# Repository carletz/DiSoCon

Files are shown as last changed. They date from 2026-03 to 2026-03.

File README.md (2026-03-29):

# ☀️ DiSoCon2 — Differential Solar Controller V2

> **A fully open-source, ESP32-S3 based differential solar thermal controller with dual-tank switching, PT1000 sensing, TRIAC pump control, and Ethernet/MQTT connectivity.**






---

## 🌡️ What Is This?

DiSoCon2 is a modular, open-hardware differential solar thermal controller designed to intelligently manage a domestic solar hot water system with **multiple storage tanks**. It replaces proprietary "dumb" controllers with a fully integrated, home-automation-aware solution built around the **ESP32-S3** and **ATmega32U4**.

The system reads four PT1000 platinum resistance sensors (solar collector, primary tank, secondary tank, return line), computes temperature differentials, and drives pumps and 3-way valves accordingly — all while reporting live data to **Home Assistant** via MQTT or **Ethernet**.

**V2 integrates the control logic and the analog temperature measurement circuitry onto a single board**, eliminating the inter-board wiring of V1 and improving signal integrity.

---

## 🎯 Key Features

| Feature | Detail |
|---|---|
| **Temperature sensing** | 4× PT1000 via precision OPV front-end (MCP6004, ±0.1% resistors) + DS18B20 OneWire bus |
| **Pump control** | 2× TRIAC outputs (BTA41-600B + MOC3021) for 230V AC pumps, with zero-cross synchronization |
| **Valve control** | 2× relay outputs (SRD-05VDC) for 3-way motorized valves, optoisolated via PC817C |
| **Connectivity** | W5500 Ethernet (SPI) + ESP32-S3 onboard WiFi/BLE |
| **Field bus** | RS-485 half-duplex via MAX13487E (auto-direction), with 120Ω termination and SMBJ6.8A TVS protection |
| **User interface** | 20×4 I2C LCD + 5-button keypad (UP / DOWN / LEFT / RIGHT / OK) read via ADS1115 |
| **Power supply** | HLK-PM01 mains-to-5V module + BL1117-33CX LDO for 3.3V logic; USB-C 5V input as alternative |
| **Safety** | Anti-freeze logic, overheating protection, fuse-protected AC input, snubber networks on all TRIAC outputs |
| **Firmware** | ESPHome YAML on ESP32-S3; ATmega32U4 Arduino firmware for analog front-end |

---

## 🧩 System Architecture

The project is split into two physically separate boards that connect via a 10-pin IDC ribbon:

```
┌─────────────────────────────────────────────────┐
│              CONTROL BOARD (Full Board V2)      │
│                                                 │
│  ┌──────────┐  ┌──────────┐  ┌───────────────┐  │
│  │ ATmega   │  │ ESP32-S3 │  │  W5500        │  │
│  │ 32U4     │◄─► (main    │  │  Ethernet     │  │
│  │ PT1000   │  │  ESPHome)│  │  Controller   │  │
│  │ front-end│  └────┬─────┘  └───────────────┘  │
│  └──────────┘       │                           │
│  ┌──────────┐  ┌────┴─────┐  ┌───────────────┐  │
│  │ MCP6004  │  │ MAX13487 │  │  ADS1115      │  │
│  │ 4ch OPV  │  │  RS-485  │  │  Button ADC   │  │
│  └──────────┘  └──────────┘  └───────────────┘  │
└─────────────────────┬───────────────────────────┘
                      │ 10-pin ribbon (CN3)
┌─────────────────────┴───────────────────────────┐
│              POWER BOARD (Power Board V2)       │
│                                                 │
│  ┌──────────┐  ┌──────────────┐  ┌───────────┐  │
│  │ HLK-PM01 │  │ 2× BTA41     │  │ 2× SRD    │  │
│  │ AC→5V    │  │ TRIAC pumps  │  │ relays    │  │
│  └──────────┘  │ + MOC3021    │  │ valves    │  │
│                │ + snubber    │  └───────────┘  │
│  ┌──────────┐  └──────────────┘                 │
│  │ ZeroCross│  MB10S bridge + LTV-817C          │
│  │ detector │  → ZEROCROSS signal to ESP32      │
│  └──────────┘                                   │
└─────────────────────────────────────────────────┘
```

<div align="center">
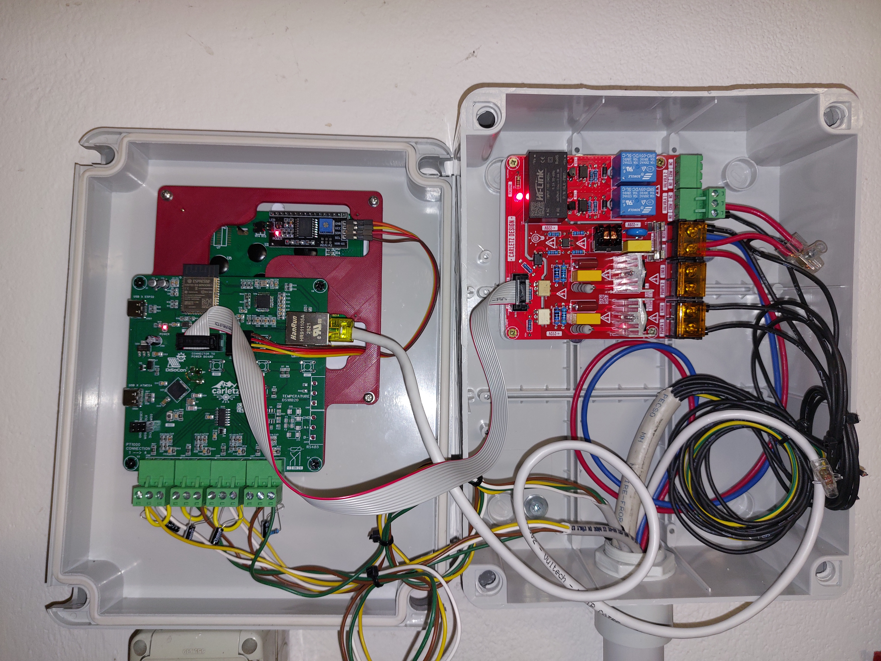
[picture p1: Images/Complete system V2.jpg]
    
</div>

---

## 📐 Hardware Details

### Control Board — Full Board V2.0 (6-page schematic)

<div align="center">
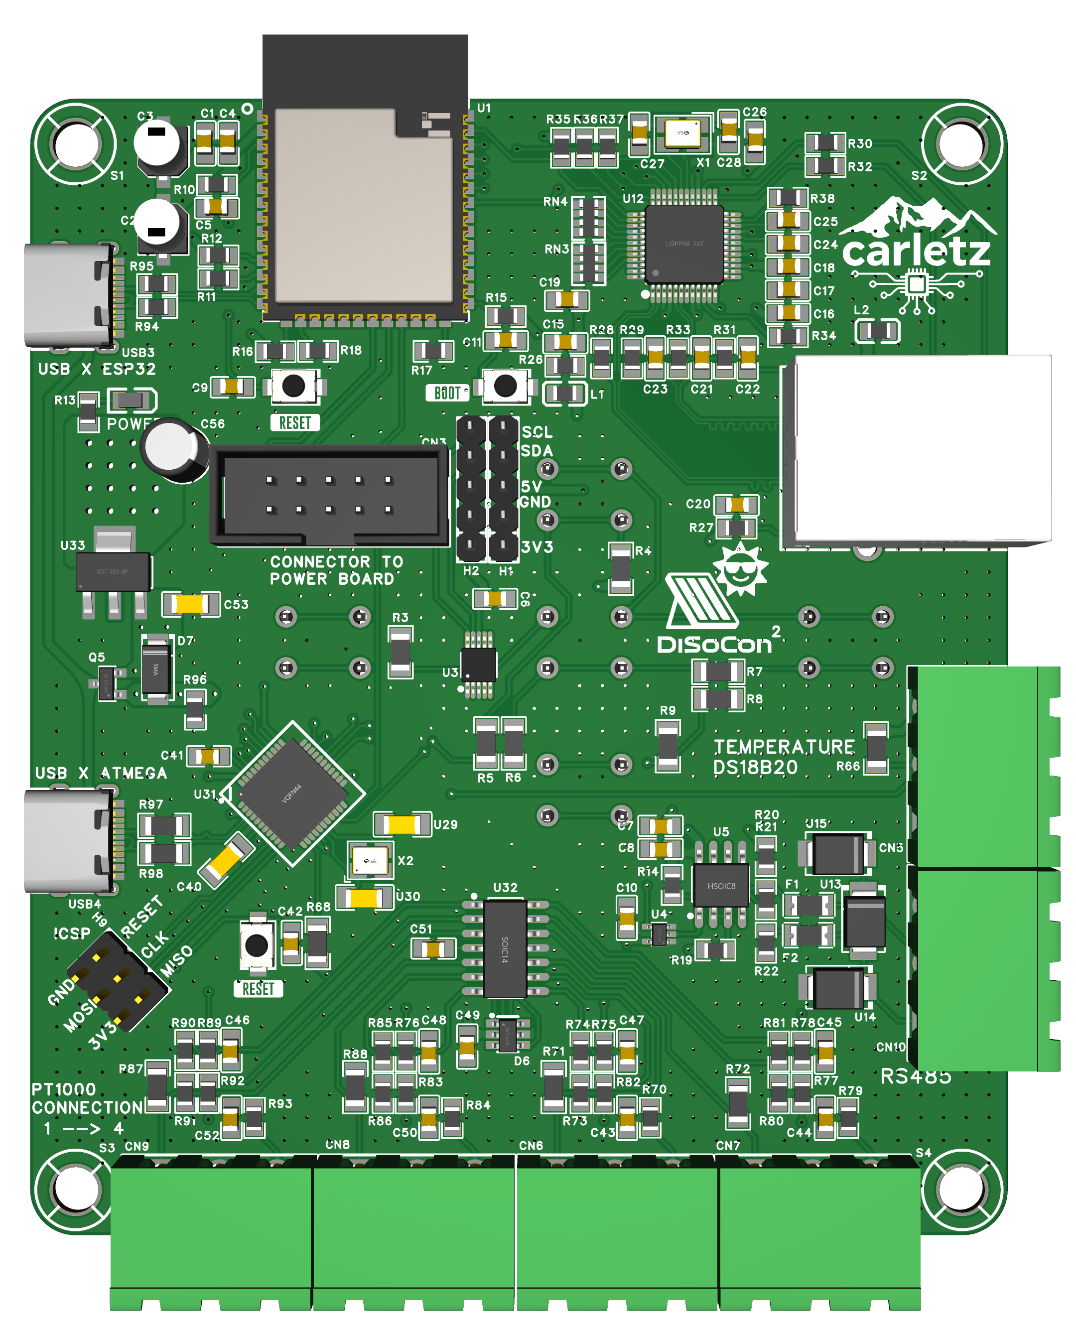
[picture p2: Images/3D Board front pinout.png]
    
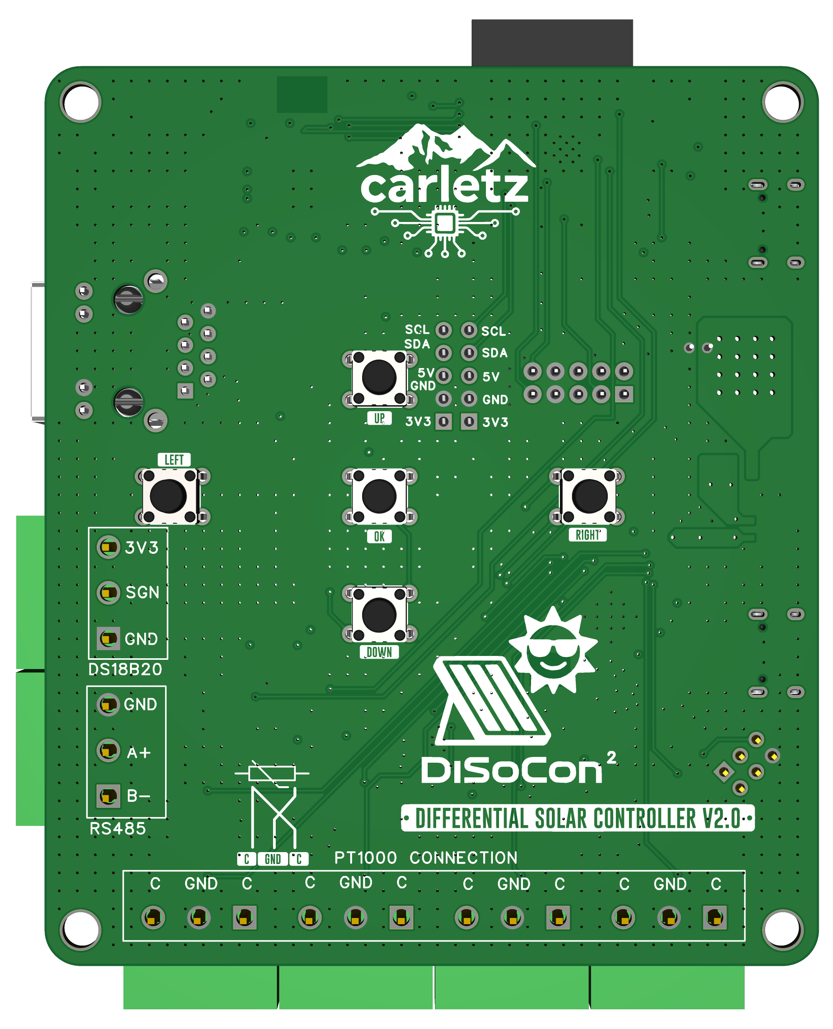
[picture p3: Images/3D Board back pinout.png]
    
</div>

#### Page 1 · Microcontroller & Power

- **ESP32-S3** (U1) — main application processor running ESPHome. Controls all outputs, reads sensors, manages Ethernet and RS-485.
- **ATmega32U4** (U31) — dedicated analog co-processor. Drives the PT1000 OPV front-end, sends converted temperature values to the ESP32-S3 via UART (`TEMP-TX` / `TEMP-RX`). Has its own USB-C (USB4) for independent firmware upload and an ICSP header (H9) for UPDI/ISP programming.
- **3.3V power**: BL1117-33CX LDO (U33) fed from the 5V rail. Protected by a WPM2015-3 P-FET ORing between USB-C 5V (USB5V) and board 5V (+5VP), with a 1N5819 Schottky for reverse-polarity protection.
- RESET and BOOT tactile buttons for ESP32-S3; RESET button also present for ATmega32U4.
- Power LED (XL-2012SURC red) on 3.3V via 1kΩ.

#### Page 2 · Ethernet

- **W5500** (U12) — hardware TCP/IP offload chip connected to ESP32-S3 via SPI1 (`SPI1_MOSI/MISO/SCK/CS`). Reset line (`RST_NET`) and interrupt line (`INT_NET`) connected to dedicated ESP32-S3 GPIOs.
- Magnetics: **HR911105A** integrated RJ45 with built-in transformer (1CT:1CT) and LEDs — LINK (yellow) and ACT (green).
- 25MHz crystal (X1) for W5500 clock. Pi-filter (HCB2012KF-121T50 ferrite beads L1/L2) on the 3.3VNET rail for noise isolation.
- Proper termination: 49.9Ω series resistors on TX pairs; 82Ω series on RX pairs; 6.8nF and 10nF AC coupling capacitors; 22nF center-tap capacitor.
- W5500 PMODE pins floating (auto-negotiate 10/100 with auto-MDIX).

#### Page 3 · I/O, PCF8574 & LCD

- **5-button keypad**: UP, DOWN, LEFT, RIGHT, OK (KH-6X6X8H-TJ tactile switches) wired to an **ADS1115** (U3) via a resistive voltage divider (1kΩ + 1MΩ pull-down). The ADS1115 reads button combinations on AIN0; ALERT/RDY can generate interrupts.
- **PCF8574M** (U9) — 8-bit I2C I/O expander that buffers output signals (MOTORE1-3, VALVOLA1-2, ZEROCROSS) to the Power Board via the **SN74HCT14** (U10) Schmitt-trigger hex inverter. Note: this path is **not suitable for PWM signals** (as marked on the schematic).
- **20×4 I2C LCD** (LCD1) connected via a standard PCF8574-based I2C backpack module.
- Two 5-pin I2C expansion headers (H1, H2) provide 3.3V / 5V, SDA, SCL for external I2C peripherals.
- 10-pin IDC connector (CN3) carries all inter-board signals: MOTORE1, MOTORE2, ZEROCROSS, VALVOLA1, VALVOLA2, 3.3V, 5V, +5VP (relay coil), GND.

#### Page 4 · RS-485

- **MAX13487EESA+T** (U5) — half-duplex RS-485 transceiver with integrated auto-direction control (no DE/RE GPIO needed). VCC at 5V, with a `SN74LVC1G125` (U4) level shifter on the RO output to convert from 5V to 3.3V logic for ESP32-S3 RX.
- **120Ω** termination resistor (R21) across A/B lines.
- **4.7kΩ** fail-safe bias resistors (R20, R22) on A and B.
- **SMBJ6.8A** TVS diodes (U13, U14, U15) on A line, B line, and GND for surge/ESD protection on the RS-485 bus.
- Self-resetting polyfuses (F1, F2: nSMD005) on A and B lines.
- Screw terminal connector (CN10: WJ2EDGRC-5.08-3P) for field wiring.

#### Page 5 · ATmega32U4

- **ATmega32U4-MU** (U31) in QFN-44 package. Clocked at 16MHz (crystal X2 with 22pF load caps U29/U30).
- USB (D+/D-) protected by a **DALC208SC6** (D8) ESD array with 22Ω series resistors (R97, R98).
- ICSP/SPI header H9 exposes MOSI, MISO, CLK, RESET for external programmer access.
- Communicates with ESP32-S3 via UART: `PD2(RXD1)` → `TEMP-RX` on ESP32; `PD3(TXD1)` → `TEMP-TX`.
- ADC pins PF0–PF7 connected to the OPV amplifier outputs (TEMP_OUT1–4) and enable signals (TEMP_ENB1–4) controlled by PC7/PC6/PB6/PB5.
- `OPV_ENB` line (PC7 / PE2) allows the ATmega to power-gate the entire OPV section.
- OneWire DS18B20 bus on a separate 3-pin screw terminal (CN5) with 4.7kΩ pull-up (R66).

#### Page 6 · PT1000 Amplifier

- **MCP6004T-I/SL** (U32) — quad rail-to-rail op-amp, all four channels used, one per PT1000 sensor.
- Each channel implements an **inverting amplifier** with gain set by a ±0.1% tolerance 9.1kΩ feedback resistor (R90/R85/R74/R81) and 1kΩ input resistor (R91/R86/R75/R80). This gives a gain of –9.1.
- 1MΩ resistors (R87/R88/R71/R72) provide a DC bias path to the non-inverting input (tied to GND reference).
- Each output is low-pass filtered: 1kΩ (R89/R76/R78/R73) + 1µF (C46/C48/C47/C45) forming a ~160Hz corner frequency to reject switching noise.
- Per-channel enable switches (`TEMP_ENB1–4`) built from 4.7kΩ / 4.7kΩ resistor pairs allow the ATmega to multiplex or disable channels individually.
- **DALC208SC6** (D6) ESD protection array on all four sensor input lines (IN+1 through IN+4) before they reach the OPV inputs.
- OPV supply (VDD/VSS) bypassed with 100nF (C51/C52), power-gated via `OPV_ENB`.
- PT1000 connectors: CN9 / CN8 / CN6 / CN7 (WJ2EDGRC-5.08-3P screw terminals, one per sensor channel).

---

### Power Board — Power Board V2.0 (2-page schematic)

<div align="center">
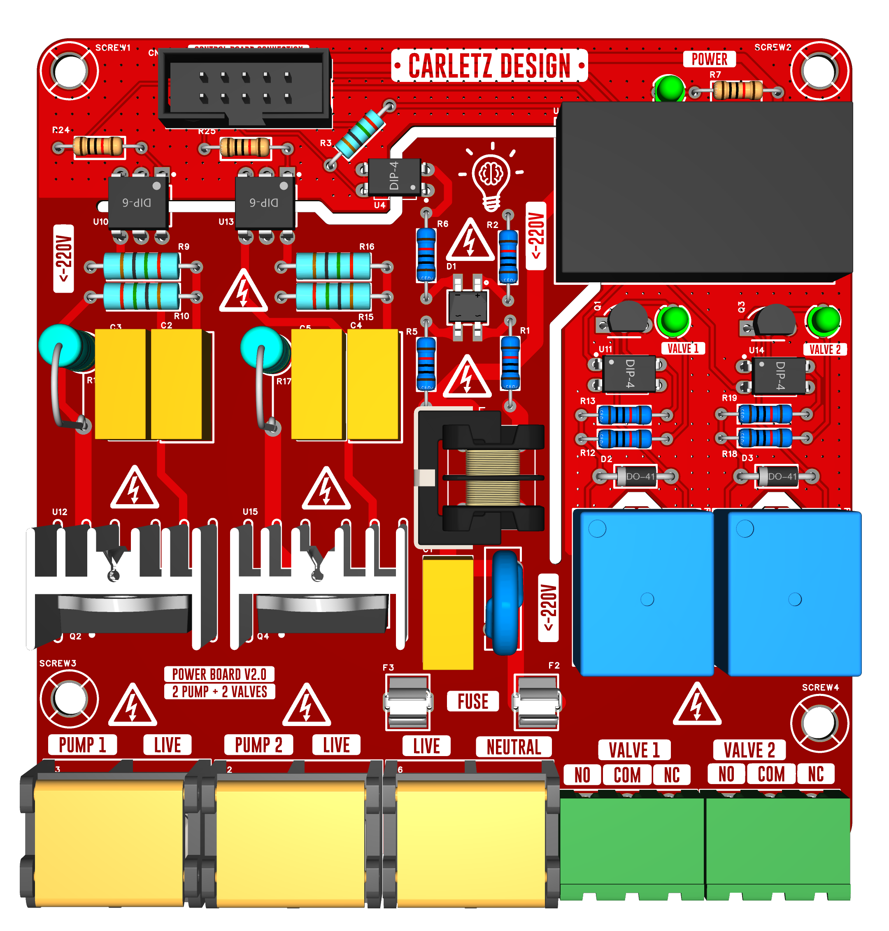
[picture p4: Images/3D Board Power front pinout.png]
    
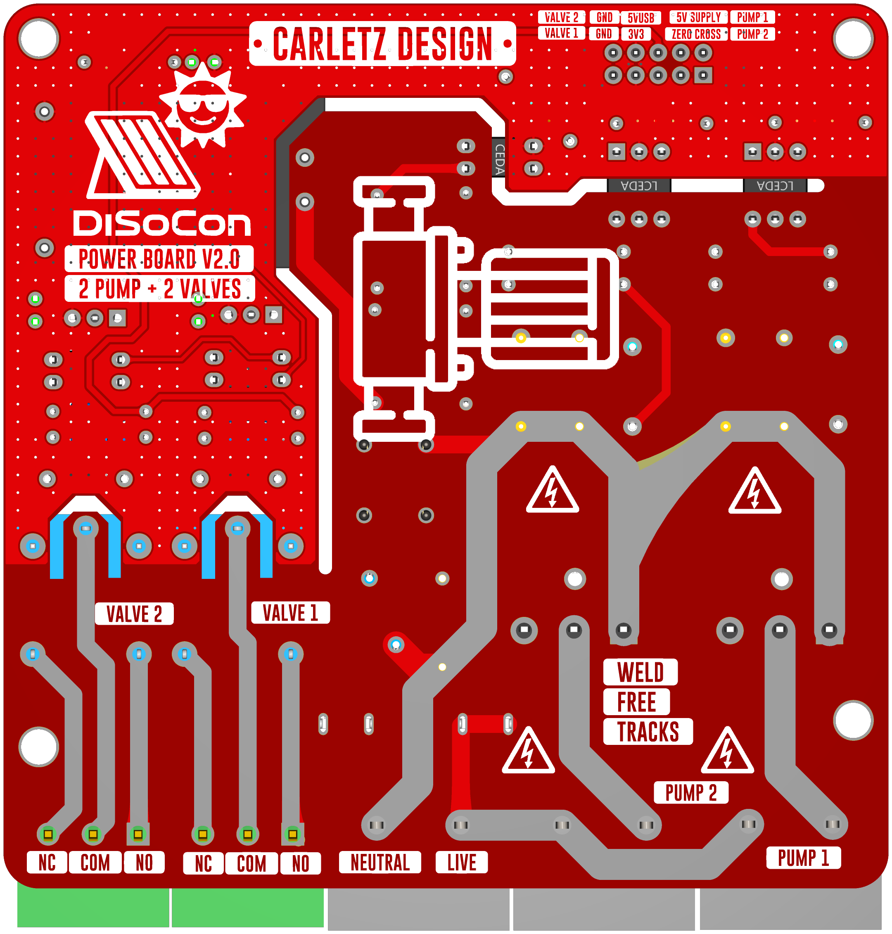
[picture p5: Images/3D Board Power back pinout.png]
    
</div>

#### Page 1 · Power Supply, Connector & Relays

- **AC mains input** enters through a 5×20mm fuse (F2/F3) and a varistor (R4: RM10D561KD24E100) + EMI filter choke (L1: UU9.8Y-10mH) before reaching the **HLK-PM01** (U8) isolated AC-DC module, which outputs 5VDC. A 100nF capacitor (C1) on the AC side suppresses differential-mode noise.
- An additional slow-blow fuse (F4: 5G.300021) provides secondary protection.
- The 5V rail powers relay coils, optocouplers, and feeds through the 10-pin IDC (CN3) to the control board.
- **POWER LED** indicator on the Power Board side.
- AC line (L, N) also distributed to motor output screw terminals (M1, M2) and to TRIAC load outputs.
- **DBT50G-9.5-2P** connectors (U2, U3, U6) for L, N, and motor output wiring.
- Four PCB screw posts (SCREW1–4) for chassis/DIN rail mounting.

**Relay section (Valve 1 & Valve 2):**
- Two identical circuits, each using:
  - **BC547** NPN transistor (Q1, Q3) to drive the relay coil from a 3.3V logic signal via 1kΩ base resistor.
  - **SRD-05VDC-SL-C** 5V SPDT relay (RLY1, RLY2) switched by the transistor.
  - **1N4007** flyback diode (D2, D3) across the relay coil.
  - **PC817C** optocoupler (U11, U14) provides galvanic isolation between logic-side (`VALVOLA1/2` signals, 3.3V-fed via 1kΩ) and the relay driver side (5VUSB referenced). Output resistor 1kΩ.
  - RELE' LED indicators (green XL-2012SURC via 220Ω) for visual relay status.
  - 3-pin screw terminal outputs (CN1, CN2) for valve wiring.

#### Page 2 · TRIAC Firing & Zero-Cross Detection

**TRIAC circuits (Pump 1 & Pump 2) — identical topology:**
- **MOC3021M** (U10, U13) — non-zero-crossing TRIAC optocoupler (zero-cross sync is handled in software using the ZEROCROSS signal). LED drive current set by 150Ω / 100Ω resistors (R24/R25) on the logic side.
- Gate current limiting resistor 360Ω (R9, R15) + snubber network: 47nF (C2/C4) + 100Ω (R11/R17) in series across the TRIAC, plus 100nF (C3/C5) across the main terminals.
- Gate-side 470Ω resistor (R10, R16) to limit peak gate current into the TRIAC.
- **BTA41-600BRG** (Q2, Q4) — 40A/600V TO-220 TRIAC. Rated far above typical domestic pump currents for long-term reliability and inrush tolerance.
- **XSD1226-307** (U12, U15) — TRIAC thermal fuse (307°C) in series with the gate resistor for thermal runaway protection.
- Output screw terminals for motors M1 and M2 (Line + Neutral).

**Zero-cross detection:**
- **MB10S** bridge rectifier (D1) connected directly across Line (LP) and Neutral (NP) through four 47kΩ resistors (R1/R2/R5/R6) as a current limiter (total ~188kΩ into a 230V mains, ≈1.2mA peak).
- **LTV-817-C** (U4) optocoupler with 10kΩ pull-up (R3) on the output side (3.3V). Generates the `ZEROCROSS` signal — a pulse train at twice the mains frequency (100Hz for 50Hz mains) that is routed to the ESP32-S3 for phase-synchronised TRIAC firing.

---

## 🔌 Inter-Board Connector Pinout (CN3 — DC3-2.54-10PAS)

| Pin | Signal | Direction | Description |
|---|---|---|---|
| 1 | MOTORE2 | PB → CB | Pump 2 control signal |
| 2 | MOTORE1 | PB → CB | Pump 1 control signal |
| 3 | ZEROCROSS | PB → CB | Zero-cross detection pulse |
| 4 | 5V | PB → CB | 5V power from HLK-PM01 |
| 5 | 3V3 | CB → PB | 3.3V logic reference |
| 6 | 5VUSB | CB → PB | USB 5V (relay coil supply) |
| 7 | — | — | (reserved/GND) |
| 8 | VALVOLA1 | CB → PB | Valve 1 control |
| 9 | VALVOLA2 | CB → PB | Valve 2 control |
| 10 | GND | — | Common ground |

> CB = Control Board, PB = Power Board

---

## 🌡️ PT1000 Sensing: Recommended Wiring

Each PT1000 connects to a 3-pin screw terminal on the Control Board (CN6–CN9). The sensor is wired in a **2-wire configuration** to the OPV input. For best accuracy, use matched cable runs and consider the per-channel gain/offset calibration available in the ATmega firmware.

| Connector | Sensor Location | Signal |
|---|---|---|
| CN9 | Solar collector (panel) | IN+1 → TEMP_OUT1 |
| CN8 | Primary storage tank | IN+2 → TEMP_OUT2 |
| CN6 | Return / secondary circuit | IN+3 → TEMP_OUT3 |
| CN7 | Secondary tank / boiler outlet | IN+4 → TEMP_OUT4 |

---

## ⚙️ Control Logic Overview

The ESP32-S3 implements the following logic layers in ESPHome:

1. **Temperature acquisition** — ATmega32U4 reads 4× PT1000 channels via the OPV front-end, applies per-channel IIR filtering and gain/offset calibration, and streams the values over UART to the ESP32-S3.
2. **Differential control (ΔT)** — Compares solar collector temperature against tank temperatures. Activates `MOTORE1` (solar pump) when ΔT exceeds a configurable threshold; deactivates with hysteresis.
3. **Dual-tank switching** — Activates `VALVOLA1` / `VALVOLA2` to direct hot fluid to the tank with the lowest temperature, maximising energy storage.
4. **Secondary pump** — `MOTORE2` manages heat exchange with the gas boiler loop based on secondary tank differentials.
5. **Protections**:
   - **Anti-freeze**: Forces pump on when collector temperature drops below a configurable minimum.
   - **Overheating**: Limits pump runtime or diverts flow when tank temperature exceeds maximum.
   - **Sensor fault**: Detects open-circuit (NaN, T < –10°C) or short-circuit (T > 200°C) PT1000 conditions.
6. **TRIAC zero-cross firing** — Pump activation is synchronised to the mains zero-crossing via the `ZEROCROSS` interrupt for reduced EMI and inrush.

<div align="center">
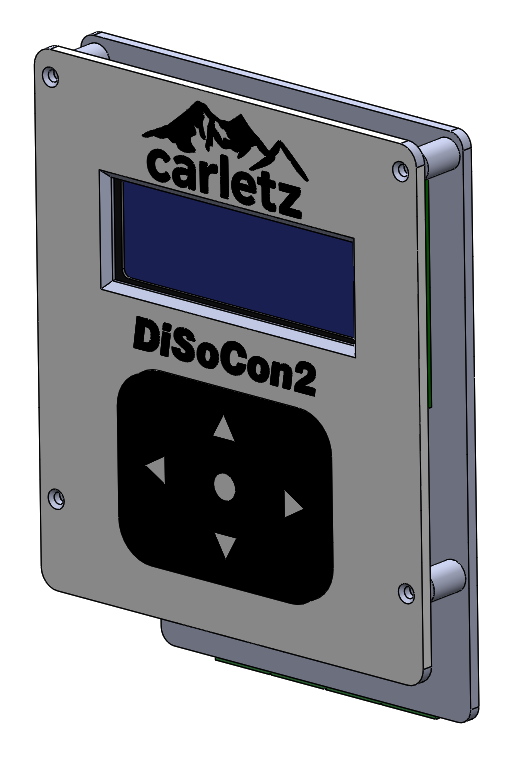
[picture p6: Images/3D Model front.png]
    
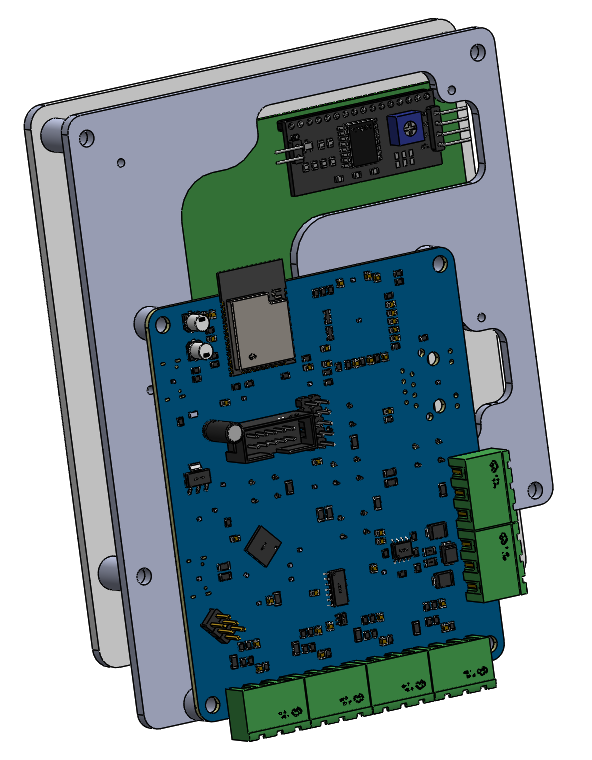
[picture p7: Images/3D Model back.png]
    
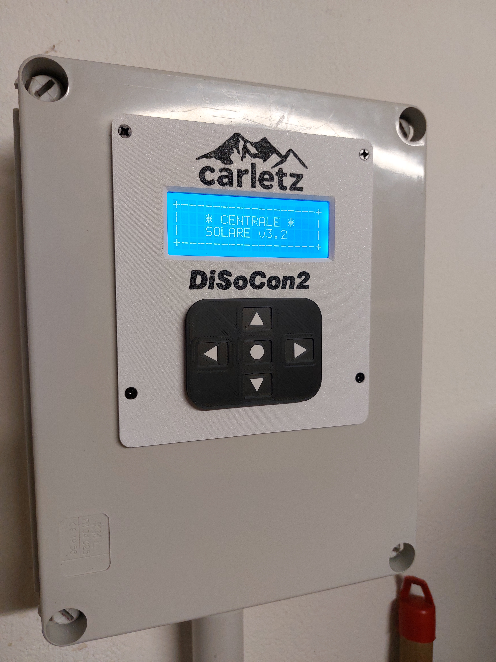
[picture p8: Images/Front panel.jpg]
    
</div>

---

## 📁 Repository Structure

```
DiSoCon/
├── 3D Model/                         # 3D renders and model files
├── Hardware/                         # Schematics, PCB Gerbers, EasyEDA sources
│   ├── SCH_Full_Board_V2.0.pdf       # Control board schematic (6 pages)
│   └── SCH_Power_Board_V2.0.pdf      # Power board schematic (2 pages)
├── Images/                           # Board renders, photos, diagrams
├── Software/                         # Firmware source code
│   ├── ESPHome YAML                  # ESPHome configuration for ESP32-S3
│   └── ATmega32U4/                   # Arduino sketch for PT1000 co-processor
├── LICENSE
└── README.md
```

---

## 🚀 Getting Started

### 1. Hardware

- Order PCBs from Gerber files (JLCPCB)
- Assemble the Power Board first; verify 5V output before connecting the Control Board
- Flash the ATmega32U4 via ICSP header H9 (Arduino Nano as ISP or dedicated programmer)
- Flash ESPHome to the ESP32-S3 via USB-C (USB3 connector)

### 2. Firmware

```bash
# Clone the repo
git clone https://github.com/carletz/DiSoCon

# Flash ESPHome (first time via USB)
esphome run Software/main.yaml

# Subsequent updates via OTA (Ethernet or WiFi)
```

### 3. Home Assistant Integration

Add the device to ESPHome dashboard. All sensors, pumps, and valve states are automatically exposed as Home Assistant entities. MQTT topics follow ESPHome conventions.

---

## ⚠️ Safety & Disclaimer

> **This project involves mains voltage (230V AC). Working with mains voltage is potentially lethal.**

This project is provided **for educational and inspiration purposes only**. The author(s) accept **no responsibility** for damage to equipment, persons, or property arising from the use of this design.

Any real-world installation must be performed by a **qualified electrician** in compliance with local electrical codes and safety regulations (e.g. IEC 60364 in Europe).

By using this material you acknowledge it is offered **as-is, without warranty of any kind**.

---

## 📅 Version History

| Version | Date | Notes |
|---|---|---|
| V2.0 | March 2026 | Integrated control + analog measurement on single board; ATmega32U4 co-processor; EasyEDA redesign |
| V1.0 | April 2025 | Separate controller and temperature measurement boards |

---

## 👤 Author

**carletz** — [@carletz on GitHub](https://github.com/carletz)

[YouTube: carletz](https://www.youtube.com/@carletzslug)

[OSHWLab: carletz](https://oshwlab.com/carletz.slug/works)

---

## 📜 License

This work — hardware schematics, PCB designs, firmware, and documentation — is licensed under the **Creative Commons Attribution-NonCommercial-ShareAlike 4.0 International License (CC BY-NC-SA 4.0)**.



**You are free to:**
- **Share** — copy and redistribute the material in any medium or format
- **Adapt** — remix, transform, and build upon the material

**Under the following terms:**
- **Attribution** — You must give appropriate credit, provide a link to the license, and indicate if changes were made.
- **NonCommercial** — You may not use the material for commercial purposes.
- **ShareAlike** — If you remix, transform, or build upon the material, you must distribute your contributions under the same license.

See [`LICENSE`](./LICENSE) for the full license text.

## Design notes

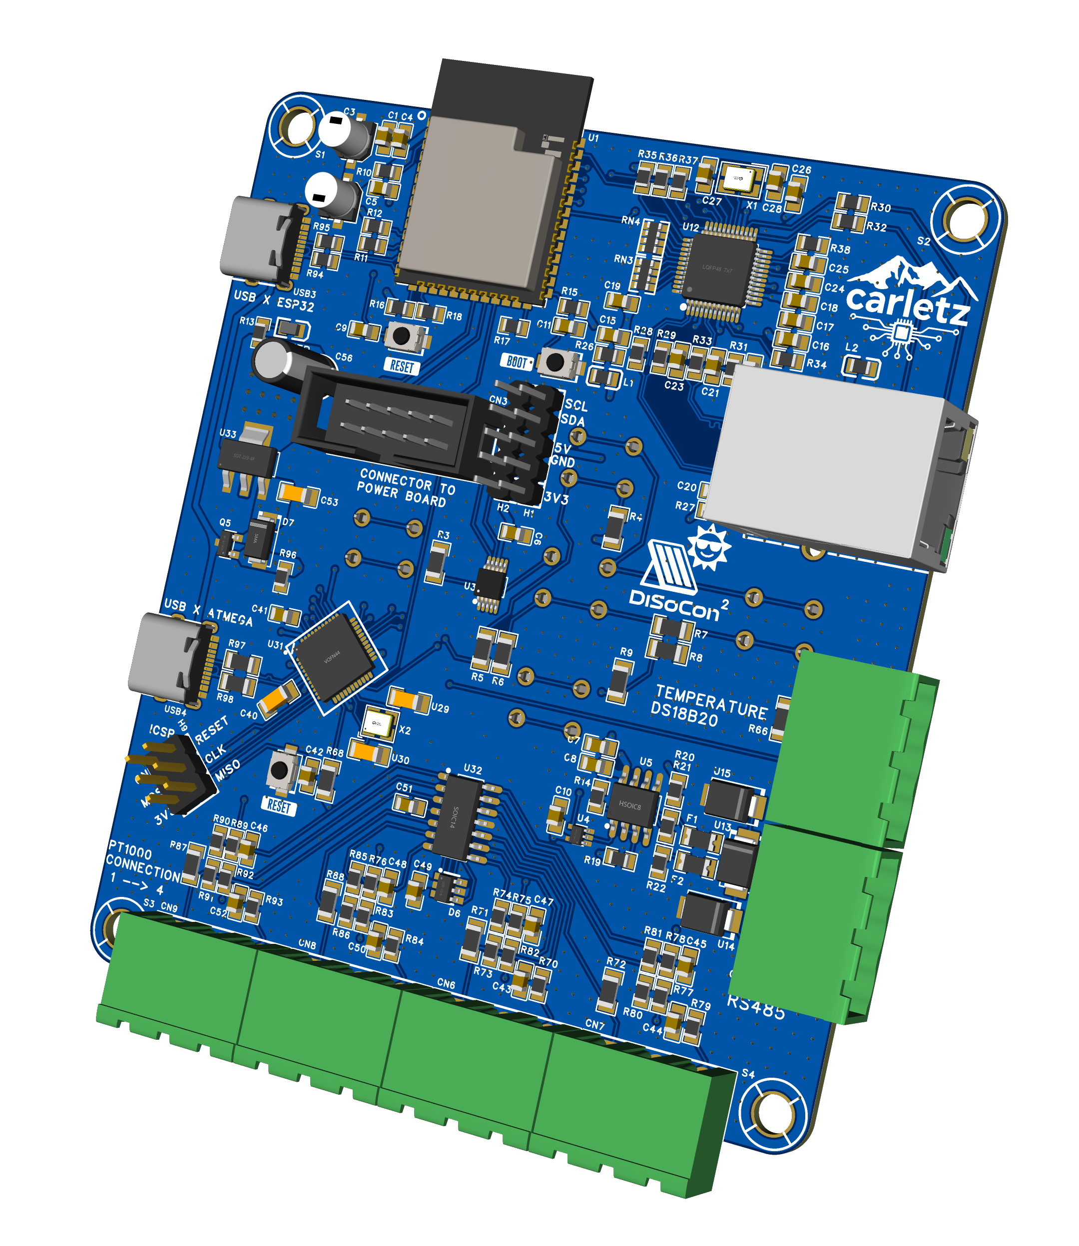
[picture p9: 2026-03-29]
Images/3D Board front.png

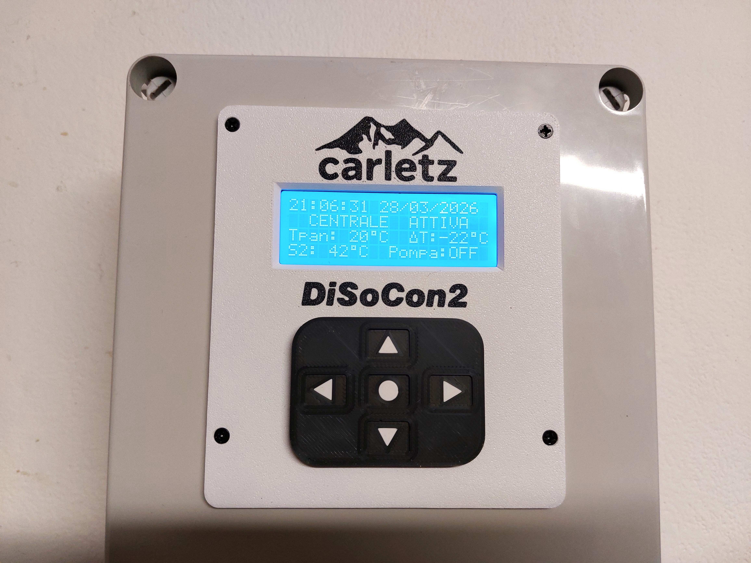
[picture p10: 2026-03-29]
Images/cover.jpg

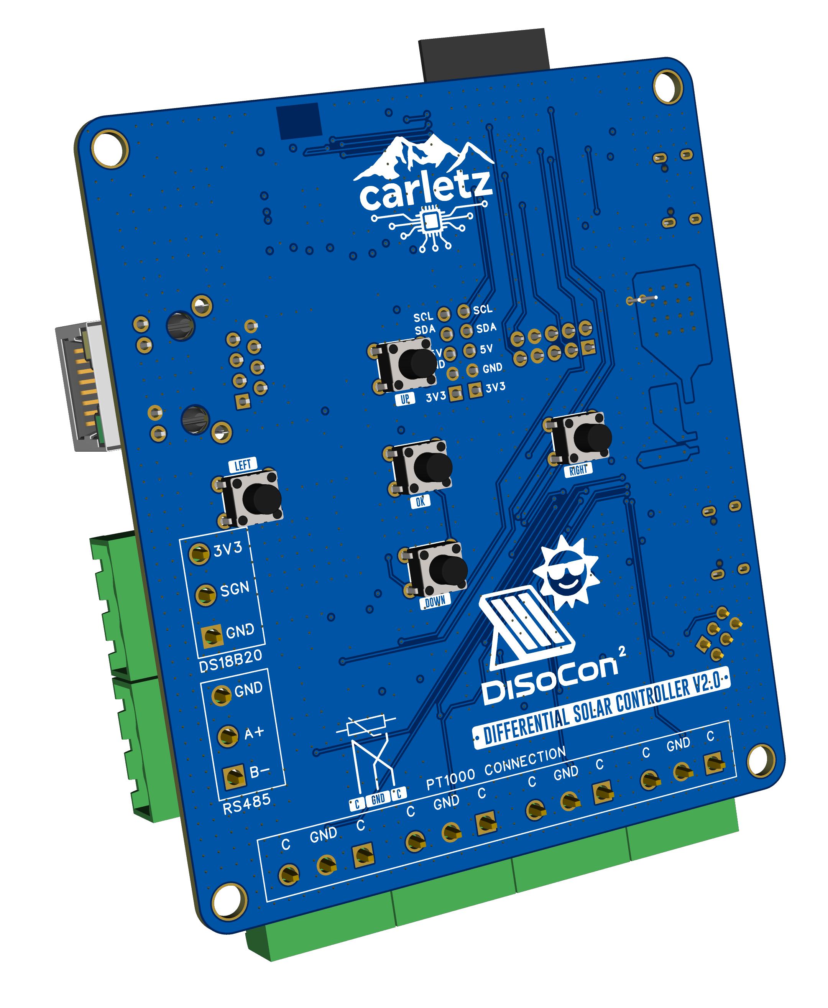
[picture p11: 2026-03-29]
Images/3D Board back.png

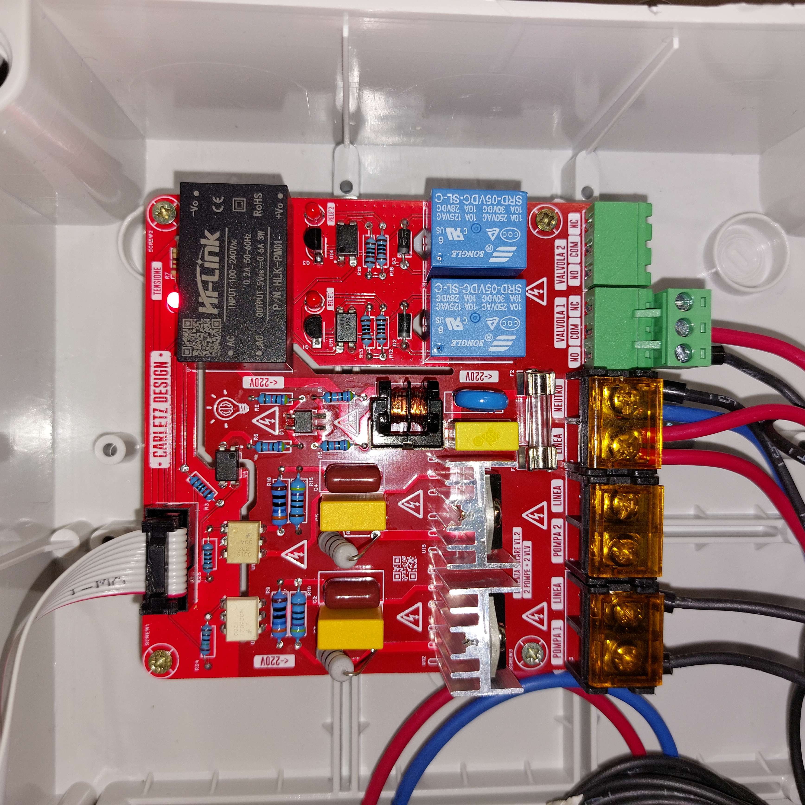
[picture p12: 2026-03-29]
Images/Power Board.jpg

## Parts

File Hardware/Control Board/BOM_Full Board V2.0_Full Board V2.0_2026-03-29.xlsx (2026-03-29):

No. | Quantity | Comment | Designator | Footprint | Value | Manufacturer Part | Manufacturer | Supplier Part | Supplier | LCSC Stock | LCSC Price | Primary Category | Secondary Category | Pin Count | JLCPCB Stock | JLCPCB Price | 3D Model Title | Device | Name | Unique ID | Convert to PCB | Add into BOM | Symbol
1 | 3 | TS-1088-AR02016 | ((BOOT)),((RESET)),((RESET)) | SW-SMD_L3.9-W3.0-P4.45 |  | TS-1088-AR02016 | XUNPU(讯普) | C720477 | LCSC |  |  | Switches | Tactile Switches | 2 | 655129 | 0.008 | SW-SMD_L3.9-W2.9-H2.0-LS4.8 | TS-1088-AR02016 | TS-1088-AR02016 | gge95,gge95_1,gge98 |  | yes
2 | 5 | KH-6X6X8H-TJ | ((DOWN)),((LEFT)),((OK)),((RIGHT)),((UP)) | SW-TH_4P-L6.0-W6.0-P4.50-LS6.5 |  | KH-6X6X8H-TJ | kinghelm(金航标) | C2837518 | LCSC |  |  | Key/Switch | Tactile Switches | 4 | 5232 | 0.0023 | SW-TH_4P-L6.0-W6.0-H7.0-P4.50-LS6.5_EVQPAE07K | KH-6X6X8H-TJ | KH-6X6X8H-TJ | gge35,gge36,gge37,gge38,gge39 |  | yes
3 | 3 | 10uF | C1,C7,C15 | C0805 | 10uF | CL21A106KOQNNNE | SAMSUNG(三星) | C1713 | LCSC |  |  | Capacitors | Multilayer Ceramic Capacitors MLCC - SMD/SMT | 2 | 1675133 | 0.0022 | C0805_L2.0-W1.3-H1.3 | CL21A106KOQNNNE | 10uF | gge199,gge200,gge201 |  | yes
4 | 2 | 10uF | C2,C3 | CAP-SMD_BD4.0-L4.3-W4.3-LS5.1-FD | 10uF | VE-100M1ATR-0405 | lelon(立隆) | C249449 | LCSC |  |  | Capacitors | Aluminum Electrolytic Capacitors - SMD | 2 | 0 | 0.009 | CAP-SMD_BD4.0-L4.3-W4.3-LS5.1-FD | VE-100M1ATR-0405 | 10uF | gge137,gge138 |  | yes
5 | 8 | 100nF | C4,C9,C11,C16,C17,C18,C19,C26 | C0805 | 100nF | CL21B104KCFNNNE | SAMSUNG(三星) | C28233 | LCSC |  |  | Capacitors | Multilayer Ceramic Capacitors MLCC - SMD/SMT | 2 | 3374865 | 0.0015 | C0805_L2.0-W1.3-H1.3 | CL21B104KCFNNNE | 100nF | gge211,gge212,gge213,gge214,gge215,gge216,gge217,gge218 |  | yes
6 | 2 | 1uF | C5,C6 | C0805 | 1uF | HHV0805R7105K101NSLJ | Chinocera(华瓷) | C22367837 | LCSC |  |  | Capacitors | Multilayer Ceramic Capacitors MLCC - SMD/SMT | 2 | 138361 | 0.0032 | C0805_L2.0-W1.3-H1.3 | HHV0805R7105K101NSLJ | 1uF | gge251,gge251_1 |  | yes
7 | 10 | 100nF | C8,C10,C41,C42,C43,C44,C49,C50,C51,C52 | C0805 | 100nF | C0805B104K500NT | TORCH(火炬) | C476766 | LCSC |  |  | Capacitors | Multilayer Ceramic Capacitors MLCC - SMD/SMT | 2 | 148715 | 0.0006 | C0805_L2.0-W1.3-H1.3 | C0805B104K500NT | 100nF | gge140,gge141,gge148,gge155,gge162,gge162_1,gge162_2,gge163,gge163_1,gge163_2 |  | yes
8 | 1 | 22nF | C20 | C0805 | 22nF | CC0805KRX7R9BB223 | YAGEO(国巨) | C107147 | LCSC |  |  | Capacitors | Multilayer Ceramic Capacitors MLCC - SMD/SMT | 2 | 399455 | 0.001 | C0805_L2.0-W1.3-H1.3 | CC0805KRX7R9BB223 | 22nF | gge255 |  | yes
9 | 2 | 6.8nF | C21,C23 | C0805 | 6.8nF | 0805B682K500NT | FH(风华) | C1755 | LCSC |  |  | Capacitors | Multilayer Ceramic Capacitors MLCC - SMD/SMT | 2 | 143347 | 0.0009 | C0805_L2.0-W1.3-H1.3 | 0805B682K500NT | 6.8nF | gge233,gge234 |  | yes
10 | 2 | 10nF | C22,C25 | C0805 | 10nF | FV21X103K102ECG | PSA(信昌电陶) | C565682 | LCSC |  |  | Capacitors | Multilayer Ceramic Capacitors MLCC - SMD/SMT | 2 | 291331 | 0.0027 | C0805_L2.0-W1.3-H1.3 | FV21X103K102ECG | 10nF | gge206,gge207 |  | yes
11 | 1 | 4.7uF | C24 | C0805 | 4.7uF | CC0805KKX7R5BB475 | YAGEO(国巨) | C520073 | LCSC |  |  | Capacitors | Multilayer Ceramic Capacitors MLCC - SMD/SMT | 2 | 34 | 0.0059 | C0805_L2.0-W1.3-H1.3 | CC0805KKX7R5BB475 | 4.7uF | gge228 |  | yes
12 | 2 | 20pF | C27,C28 | C0805 | 20pF | TCC0805COG200J500BT | CCTC(三环) | C309037 | LCSC |  |  | Capacitors | Multilayer Ceramic Capacitors MLCC - SMD/SMT | 2 | 115681 | 0.0008 | C0805_L2.0-W1.3-H1.3 | TCC0805COG200J500BT | 20pF | gge229,gge230 |  | yes
13 | 1 | 1uF | C40 | C1206 | 1uF | CL31B105KCHNNNE | SAMSUNG(三星) | C13832 | LCSC |  |  | Capacitors | Multilayer Ceramic Capacitors MLCC - SMD/SMT | 2 | 431808 | 0.0042 | C1206_L3.2-W1.6-H1.3 | CL31B105KCHNNNE | 1uF | gge93_1 |  | yes
14 | 4 | 1uF | C45,C46,C47,C48 | C0805 | 1uF | 0805B105K500NT | FH(风华) | C215803 | LCSC |  |  | Capacitors | Multilayer Ceramic Capacitors MLCC - SMD/SMT | 2 | 2339686 | 0.0016 | C0805_L2.0-W1.3-H1.3 | 0805B105K500NT_C215803 | 1uF | gge139,gge143,gge150,gge157 |  | yes
15 | 1 | 10uF | C53 | C1206 | 10uF | CL31A106KBHNNNE | SAMSUNG(三星) | C13585 | LCSC |  |  | Capacitors | Multilayer Ceramic Capacitors MLCC - SMD/SMT | 2 | 2157146 | 0.0091 | C1206_L3.2-W1.6-H1.3 | CL31A106KBHNNNE | 10uF | gge48_1 |  | yes
16 | 1 | 100uF | C56 | CAP-TH_BD5.0-P2.00-D0.5-FD-1 | 100uF | KM1A101M0507 | ROQANG(容强) | C2874000 | LCSC |  |  | Capacitors | Aluminum Electrolytic Capacitors - Leaded | 2 | 0 |  | CAP-TH_BD5.0-P2.00-D0.5-FD-1 | KM1A101M0507 | 100uF | gge304 |  | yes
17 | 1 | DC3-2.54-10PAS | CN3 | CONN-TH_10P-P2.54_DC3-2.54-10PAS |  | DC3-2.54-10PAS | ZHOURI(洲日) | C2977596 | LCSC |  |  | Connectors | IDC Connectors | 10 | 8902 | 0.0119 | CONN-TH_10P-P2.54_DC3-2.54-10PAS | DC3-2.54-10PAS | DC3-2.54-10PAS | gge119 |  | yes
18 | 6 | WJ2EDGRC-5.08-3P | CN5,CN6,CN7,CN8,CN9,CN10 | CONN-TH_3P-P5.08_WJ2EDGRC-5.08-3P |  | WJ2EDGRC-5.08-3P | KANGNEX(康奈克斯电气) | C8377 | LCSC |  |  | Connectors | Pluggable System Terminal Block | 3 | 26637 | 0.0106 | CONN-TH_WJ5.08-WI-3P-4 | WJ2EDGRC-5.08-3P_C8377 | WJ2EDGRC-5.08-3P | gge50_1,UNIQUECN51_1,UNIQUECN51_2,UNIQUECN51_3,UNIQUECN51_4,UNIQUECN51_5 |  | yes
19 | 1 | DALC208SC6 | D6 | SOT-23-6_L2.9-W1.6-P0.95-LS2.8-BR |  | DALC208SC6 | ST(意法半导体) | C54343 | LCSC |  |  | Circuit Protection | ESD and Surge Protection (TVS/ESD) | 6 | 2134 | 0.0242 | SOT-23-6_L2.9-W1.6-H1.5-LS2.8-P0.95 | DALC208SC6_C54343 | DALC208SC6 | gge134 |  | yes
20 | 1 | 1N5819 | D7 | SMA_L4.4-W2.6-LS5.0-RD |  | 1N5819 | KEXIN(科信) | C437199 | LCSC |  |  | Diodes | Schottky Barrier Diodes (SBD) | 2 | 184362 | 0.003 | SMA_L4.4-W2.6-LS5.0-RD | 1N5819_C437199 | 1N5819 | gge261_1 |  | yes
21 | 2 | nSMD005 | F1,F2 | F1206 |  | nSMD005 | 台湾陆海 | C70064 | LCSC |  |  | Circuit Protection | Resettable Fuses | 2 | 566279 | 0.005 | F1206_L3.2-W1.7-H0.6 | nSMD005_C70064 | nSMD005 | gge180,gge183 |  | yes
22 | 2 | HDR-M_2.54_1x5P | H1,H2 | HDR-TH_5P-P2.54-V-M |  |  |  |  |  |  | 7.2393 | Connectors | Pin Headers | 5 |  |  | HDR-TH_5P-P2.54-M-LI-1X5P | HDR-M_2.54_1x5P |  | gge256,gge257 |  | yes
23 | 1 | HDR-M_2.54_2x3 | H9 | HDR-TH_6P-P2.54-V-R2-C3-S2.54_A2541WV-2X3P |  |  |  |  |  |  | 7.2393 | Connectors | Pin Headers | 6 |  |  | HDR2.54-M-LI-2x3P | HDR-M_2.54_2x3 |  | gge199_3 |  | yes
24 | 1 | HR911105A | J1 | RJ45-TH_HR911105A |  | HR911105A | HANRUN(汉仁) | C12074 | LCSC |  |  | Connectors | Ethernet Connectors/Modular Connectors (RJ45 RJ11) | 14 | 114577 | 0.2183 | RJ45-TH_HR911105A | HR911105A_C12074 | HR911105A | gge127 |  | yes
25 | 2 | HCB2012KF-121T50 | L1,L2 | L0805 |  | HCB2012KF-121T50 | TAI-TECH(台庆) | C304323 | LCSC |  |  | Filters | Ferrite Beads | 2 | 245042 | 0.002 | R0805_L2.0-W1.3-H0.6 | HCB2012KF-121T50 | HCB2012KF-121T50 | gge241,gge242 |  | yes
26 | 1 | XL-2012SURC | POWER | LED0805-R-RD |  | XL-2012SURC | XINGLIGHT(成兴光) | C965812 | LCSC |  |  | Optoelectronics | LED Indication - Discrete | 2 | 2506007 | 0.0011 | LED0805-RD | XL-2012SURC | XL-2012SURC | gge156_5 |  | yes
27 | 1 | WPM2015-3/TR | Q5 | SOT-23-3_L2.9-W1.3-P1.90-LS2.4-BR |  | WPM2015-3/TR | KUU | C6562215 | LCSC |  |  | Transistors/Thyristors | MOSFETs | 3 | 12501 | 0.0047 | SOT-23-3P_L2.9-W1.3-H1.0-LS2.4-P0.95 | WPM2015-3/TR_C6562215 | WPM2015-3/TR | gge262 |  | yes
28 | 6 | 1MΩ | R3,R68,R71,R72,R87,R88 | R1206 | 1MΩ | 1206W4F1004T5E | UNI-ROYAL(厚声) | C17927 | LCSC |  |  | Resistors | Chip Resistor - Surface Mount | 2 | 1562942 | 0.0006 | R1206_L3.2-W1.6-H0.6 | 1206W4F1004T5E | 1MΩ | gge128_1,gge128_2,gge128_3,gge128_4,gge190_1,UNIQUER115 |  | yes
29 | 6 | 1kΩ | R4,R5,R6,R7,R8,R9 | R1206 | 1kΩ | 1206W4F1001T5E | UNI-ROYAL(厚声) | C4410 | LCSC |  |  | Resistors | Chip Resistor - Surface Mount | 2 | 2037201 | 0.0007 | R1206_L3.2-W1.6-H0.6 | 1206W4F1001T5E_C4410 | 1kΩ | UNIQUER109,UNIQUER110,UNIQUER111,UNIQUER112,UNIQUER113,UNIQUER114 |  | yes
30 | 13 | 10kΩ | R10,R11,R12,R14,R15,R16,R17,R18,R19,R35,R36,R37,R38 | R0805 | 10kΩ | RC0805FR-7W10KL | YAGEO(国巨) | C723404 | LCSC |  |  | Resistors | Chip Resistor - Surface Mount | 2 | 7536 | 0.0009 | R0805_L2.0-W1.3-H0.6 | RC0805FR-7W10KL | 10kΩ | gge202,gge203,gge204,gge205,gge220,gge221,gge222,gge223,gge224,gge225,gge226,gge244,gge245 |  | yes
31 | 1 | 1kΩ | R13 | R0805 | 1kΩ | 0805W8F1001T5E | UNI-ROYAL(厚声) | C17513 | LCSC |  |  | Resistors | Chip Resistor - Surface Mount | 2 | 8031915 | 0.0004 | R0805_L2.0-W1.3-H0.6 | 0805W8F1001T5E | 1kΩ | gge254 |  | yes
32 | 2 | 4.7kΩ | R20,R22 | R0805 | 4.7kΩ | 0805W8F4701T5E | UNI-ROYAL(厚声) | C17673 | LCSC |  |  | Resistors | Chip Resistor - Surface Mount | 2 | 5842566 | 0.0003 | R0805_L2.0-W1.3-H0.6 | 0805W8F4701T5E | 4.7kΩ | gge246,gge247 |  | yes
33 | 1 | 120Ω | R21 | R0805 | 120Ω | 0805W8F1200T5E | UNI-ROYAL(厚声) | C17437 | LCSC |  |  | Resistors | Chip Resistor - Surface Mount | 2 | 1356495 | 0.0004 | R0805_L2.0-W1.3-H0.6 | 0805W8F1200T5E | 120Ω | gge248 |  | yes
34 | 1 | 0Ω | R26 | R0805 | 0Ω | 0805W8F0000T5E | UNI-ROYAL(厚声) | C17477 | LCSC |  |  | Resistors | Chip Resistor - Surface Mount | 2 | 5892286 | 0.0004 | R0805_L2.0-W1.3-H0.6 | 0805W8F0000T5E_C17477 | 0Ω | gge240 |  | yes
35 | 3 | 10Ω | R27,R94,R95 | R0805_NEW | 10Ω | 0805W8F100JT5E | UNI-ROYAL(厚声) | C17415 | LCSC |  |  | Resistors | Chip Resistor - Surface Mount | 2 | 3216554 | 0.0004 | R0805_L2.0-W1.3-H0.6 | 0805W8F100JT5E | 10Ω | gge239,gge249_1,gge250_1 |  | yes
36 | 2 | 49.9Ω | R28,R29 | R0805 | 49.9Ω | 0805W8F499JT5E | UNI-ROYAL(厚声) | C17720 | LCSC |  |  | Resistors | Chip Resistor - Surface Mount | 2 | 242917 | 0.0004 | R0805_L2.0-W1.3-H0.6 | 0805W8F499JT5E | 49.9Ω | gge237,gge238 |  | yes
37 | 2 | 510Ω | R30,R32 | R0805 | 510Ω | FRC0805J511 TS | FOJAN(富捷) | C2907333 | LCSC |  |  | Resistors | Chip Resistor - Surface Mount | 2 | 944205 | 0.0003 | R0805_L2.0-W1.3-H0.6 | FRC0805J511 TS | 510Ω | gge235,gge236 |  | yes
38 | 2 | 82Ω | R31,R33 | R0805 | 82Ω | RC0805FR-0782RL | YAGEO(国巨) | C141699 | LCSC |  |  | Resistors | Chip Resistor - Surface Mount | 2 | 3434 | 0.0004 | R0805_L2.0-W1.3-H0.6 | RC0805FR-0782RL | 82Ω | gge231,gge232 |  | yes
39 | 1 | 12.4kΩ | R34 | R0805 | 12.4kΩ | 0805W8F1242T5E | UNI-ROYAL(厚声) | C30908 | LCSC |  |  | Resistors | Chip Resistor - Surface Mount | 2 | 101771 | 0.0004 | R0805_L2.0-W1.3-H0.6 | 0805W8F1242T5E | 12.4kΩ | gge243 |  | yes
40 | 1 | 4.7kΩ | R66 | R1206 | 4.7kΩ | 1206W4F4701T5E | UNI-ROYAL(厚声) | C17936 | LCSC |  |  | Resistors | Chip Resistor - Surface Mount | 2 | 1369925 | 0.0006 | R1206_L3.2-W1.6-H0.6 | 1206W4F4701T5E | 4.7kΩ | gge49_1 |  | yes
41 | 8 | 4.7kΩ | R70,R77,R79,R82,R83,R84,R92,R93 | R0805 | 4.7kΩ | ARG05BTC4701 | Viking(光颉) | C515732 | LCSC |  |  | Resistors | Chip Resistor - Surface Mount | 2 | 5986 | 0.0053 | R0805_L2.0-W1.3-H0.6 | ARG05BTC4701 | 4.7kΩ | gge137_1,gge138_1,gge146,gge147,gge152,gge153,gge160,gge161 |  | yes
42 | 4 | 1kΩ | R73,R80,R86,R91 | R0805 | 1kΩ | RT0805BRD071KL | YAGEO(国巨) | C110774 | LCSC |  |  | Resistors | Chip Resistor - Surface Mount | 2 | 124273 | 0.0052 | R0805_L2.0-W1.3-H0.6 | RT0805BRD071KL | 1kΩ | gge136,gge145,gge154,gge159 |  | yes
43 | 4 | ±0.1% 9.1kΩ | R74,R81,R85,R90 | R0805 | ±0.1% 9.1kΩ | TC0525B9101T5G | UNI-ROYAL(厚声) | C21571502 | LCSC |  |  | Resistors | Chip Resistor - Surface Mount | 2 | 2894 | 0.0044 | R0805_L2.0-W1.3-H0.6 | ARG05BTC4701 | ±0.1% 9.1kΩ | gge132,gge144,gge151,gge158 |  | yes
44 | 4 | 1kΩ | R75,R76,R78,R89 | R0805 | 1kΩ | 0805W8J0102T5E | UNI-ROYAL(厚声) | C25623 | LCSC |  |  | Resistors | Chip Resistor - Surface Mount | 2 | 3234563 | 0.0003 | R0805_L2.0-W1.3-H0.6 | 0805W8J0102T5E | 1kΩ | gge133,gge142,gge149,gge156 |  | yes
45 | 1 | 10kΩ | R96 | R0805 | 10kΩ | RC0805FR-7W10KL | YAGEO(国巨) | C17414 | LCSC |  |  | Resistors | Chip Resistor - Surface Mount | 2 | 13575158 | 0.0004 | R0805_L2.0-W1.3-H0.6 | RC0805FR-7W10KL | 10kΩ | gge224_1 |  | yes
46 | 2 | 22Ω | R97,R98 | R1206 | 22Ω | 1206W4F220JT5E | UNI-ROYAL(厚声) | C17958 | LCSC |  |  | Resistors | Chip Resistor - Surface Mount | 2 | 420899 | 0.0007 | R1206_L3.2-W1.6-H0.6 | 1206W4F220JT5E | 22Ω | gge188_2,gge189_1 |  | yes
47 | 2 | 10kΩ | RN3,RN4 | RES-ARRAY-SMD_0603-8P-L3.2-W1.6-BL | 10kΩ | 4D03WGJ0103T5E | UNI-ROYAL(厚声) | C29718 | LCSC |  |  | Resistors | Resistor Networks, Arrays | 8 | 908124 | 0.0012 | R0603-8P_L3.2-W1.6-H0.6 | 4D03WGJ0103T5E | 10kΩ | gge208,gge210 |  | yes
48 | 1 | 2.4GHz | U1 | WIRELM-SMD_ESP32-S3-WROOM-1 | 2.4GHz | ESP32-S3-WROOM-1-N8R2 | ESPRESSIF(乐鑫) | C2913204 | LCSC |  |  | IoT/Communication Modules | WiFi Modules | 49 | 12425 | 0.7122 | WIFIM-SMD_ESP32-SL | ESP32-S3-WROOM-1-N8R2 | 2.4GHz | gge102 |  | yes
49 | 1 | ADS1115IDGSR | U3 | MSOP-10_L3.0-W3.0-P0.50-LS5.0-BL |  | ADS1115IDGSR | TI(德州仪器) | C37593 | LCSC |  |  | Data Acquisition | Analog to Digital Converters (ADC) | 10 | 2574 | 0.2688 | MSOP-10_L3.0-W3.0-H1.1-LS5.0-P0.50 | ADS1115IDGSR | ADS1115IDGSR | gge190 |  | yes
50 | 1 | SN74LVC1G125DCKR | U4 | SOT-353_L2.2-W1.4-P0.65-LS2.4-BR |  | SN74LVC1G125DCKR | TI(德州仪器) | C7833 | LCSC |  |  | Logic | Buffers, Drivers, Receivers, Transceivers | 5 | 36700 | 0.0153 | SOT-353-5P_L2.0-W1.3-H1.1-LS2.0-P0.65 | SN74LVC1G125DCKR | SN74LVC1G125DCKR | gge179 |  | yes
51 | 1 | MAX13487EESA+T | U5 | SOIC-8_L4.9-W3.9-P1.27-LS6.0-BL |  | MAX13487EESA+T | ADI(亚德诺)/MAXIM(美信) | C18347 | LCSC |  |  | Interface | RS-485 / RS-422 ICs | 8 | 15215 | 0.1563 | HSOIC-8_L4.9-W3.9-H1.7-LS6.0-P1.27 | MAX13487EESA+T | MAX13487EESA+T | gge178 |  | yes
52 | 1 | W5500 | U12 | LQFP-48_L7.0-W7.0-P0.50-LS9.0-BL |  | W5500 | WIZNET | C32843 | LCSC |  |  | Interface | Ethernet Controllers | 48 | 45117 | 0.4113 | LQFP-48_L7.0-W7.0-H1.4-LS9.0-P0.50 | W5500 | W5500 | gge86 |  | yes
53 | 3 | SMBJ6.8A | U13,U14,U15 | SMB_L4.5-W3.7-LS5.4-RD |  | SMBJ6.8A | UMW(友台半导体) | C3001971 | LCSC |  |  | Circuit Protection | ESD and Surge Protection (TVS/ESD) | 2 | 6569 | 0.0054 | SMB_L4.5-W3.7-LS5.4-RD | SMBJ6.8A_C3001971 | SMBJ6.8A | gge258,gge259,gge260 |  | yes
54 | 2 | 22pF | U29,U30 | C1206 | 22pF | FCC1206N220J102DT | FOJAN(富捷) | C5137630 | LCSC |  |  | Capacitors | Multilayer Ceramic Capacitors MLCC - SMD/SMT | 2 | 35538 | 0.0022 | C1206_L3.2-W1.6-H1.3 | FCC1206N220J102DT | 22pF | gge192,gge193 |  | yes
55 | 1 | ATMEGA32U4-MU | U31 | VQFN-44_L7.0-W7.0-P0.50-BL-EP5.2 |  | ATMEGA32U4-MU | MICROCHIP(美国微芯) | C112161 | LCSC |  |  | Embedded Processors & Controllers | Microcontrollers (MCU/MPU/SOC) | 45 | 1074 | 0.8275 | VQFN-44_L7.0-W7.0-H1.0-P0.50 | ATMEGA32U4-MU | ATMEGA32U4-MU | gge187_1 |  | yes
56 | 1 | MCP6004T-I/SL | U32 | SOIC-14_L8.7-W3.9-P1.27-LS6.0-BL |  | MCP6004T-I/SL | MICROCHIP(美国微芯) | C7378 | LCSC |  |  | Amplifiers/Comparators | Operational Amplifier | 14 | 54056 | 0.0707 | SOIC-14_L8.6-W3.9-H1.8-LS6.0-P1.27 | MCP6004T-I/SL | MCP6004T-I/SL | gge131_1 |  | yes
57 | 1 | BL1117-33CX | U33 | SOT-223-4_L6.5-W3.5-P2.30-LS7.0-BR |  | BL1117-33CX | BL(上海贝岭) | C5400 | LCSC |  |  | Power Management (PMIC) | Voltage Regulators - Linear, Low Drop Out (LDO) Regulators | 4 | 63389 | 0.0081 | SOT-223-4P_L6.5-W3.5-H1.6-LS7.0-P2.30 | BL1117-33CX | BL1117-33CX | gge46_3 |  | yes
58 | 2 | TYPE-C 16PIN 2MD(073) | USB3,USB4 | USB-C-SMD_TYPE-C-6PIN-2MD-073 |  | TYPE-C 16PIN 2MD(073) | SHOU HAN(首韩) | C2765186 | LCSC |  |  | Connectors | USB Connectors | 16 | 999093 | 0.0096 | USB-C-SMD_TYPE-C-6PIN-2MD-073 | TYPE-C 16PIN 2MD(073) | TYPE-C 16PIN 2MD(073) | gge130_1,gge130_3 |  | yes
59 | 1 | 25MHz | X1 | CRYSTAL-SMD_4P-L3.2-W2.5-BL | 25MHz | X322525MOB4SI | YXC(扬兴晶振) | C9006 | LCSC |  |  | Crystals, Oscillators, Resonators | Crystals | 4 | 550487 | 0.0107 | OSC-SMD_4P-L3.2-W2.5-H1.0 COPY | X322525MOB4SI | 25MHz | gge131 |  | yes
60 | 1 | 16MHz | X2 | OSC-SMD_4P-L3.2-W2.5-BL | 16MHz | X322516MLB4SI | YXC(扬兴晶振) | C13738 | LCSC |  |  | Crystals, Oscillators, Resonators | Crystals | 4 | 461352 | 0.0105 | OSC-SMD_4P-L3.2-W2.5-H1.0 COPY | X322516MLB4SI | 16MHz | gge191 |  | yes

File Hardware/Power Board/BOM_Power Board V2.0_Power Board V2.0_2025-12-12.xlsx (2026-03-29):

No. | Quantity | Comment | Designator | Footprint | Value | Manufacturer Part | Manufacturer | Supplier Part | Supplier | LCSC Stock | LCSC Price | Primary Category | Secondary Category | Pin Count | JLCPCB Stock | JLCPCB Price | 3D Model Title | Device | Name | Unique ID | Convert to PCB | Add into BOM | Symbol | Layer | Mounting Style
1 | 3 | LED_TH-G_3mm | ((POWER)),((VALVE 1)),((VALVE 2)) | LED-TH_BD3.0-P2.54-FD |  |  |  |  |  |  | 0.0078 | Optoelectronics | Light Emitting Diodes (LED) | 2 |  |  | LED-TH_BD3.0_Green | LED_TH-G_3mm |  | gge1,gge2,gge3 |  | yes |  | T | DIP
2 | 1 | 100nF | C1 | CAP-TH_L13.0-W6.0-P10.00-D1.2 | 100nF | X2P2104KN1B0130120060ES0 | STE(松田) | C286020 | LCSC |  |  | Capacitors | Suppression Capacitors | 2 | 556 | 0.0081 | CAP-TH_L13.0-W6.0-H12.0-P10.0 | X2P2104KN1B0130120060ES0 | 100nF | UNIQUEC29 |  | yes |  | T | DIP
3 | 2 | 47nF | C2,C4 | CAP-TH_L13.5-W6.5-P10.00-D1.2 | 47nF | MEF473J630D02 | Jimson(智新) | C434327 | LCSC |  |  | Capacitors | Film Capacitors | 2 | 513 | 0.0136 | CAP-TH_L13.0-W6.0-H12.0-P10.0 | MEF473J630D02 | 47nF | UNIQUEC23,UNIQUEC24 |  | yes |  | T | DIP
4 | 2 | 100nF | C3,C5 | CAP-TH_L13.0-W6.0-P10.00-D0.6 | 100nF | MPX104K31C3KN15600 | KNSCHA(科尼盛) | C489079 | LCSC |  |  | Capacitors | Suppression Capacitors | 2 | 34920 | 0.0048 | CAP-TH_L13.0-W6.0-H12.0-P10.0 | MPX104K31C3KN15600 | 100nF | UNIQUEC26,UNIQUEC27 |  | yes |  | T | DIP
5 | 2 | WJ2EDGRC-5.08-3P | CN1,CN2 | CONN-TH_3P-P5.08_WJ2EDGRC-5.08-3P |  | WJ2EDGRC-5.08-3P | KANGNEX(康奈克斯电气) | C8377 | LCSC |  |  | Connectors | Pluggable System Terminal Block | 3 | 41741 | 0.009 | CONN-TH_WJ5.08-WI-3P-4 | WJ2EDGRC-5.08-3P_C8377 | WJ2EDGRC-5.08-3P | UNIQUECN50,UNIQUECN51 |  | yes |  | T | DIP
6 | 1 | DC3-2.54-10PAS | CN3 | CONN-TH_10P-P2.54_DC3-2.54-10PAS |  | DC3-2.54-10PAS | ZHOURI(洲日) | C2977596 | LCSC |  |  | Connectors | IDC Connectors | 10 | 13054 | 0.0104 | CONN-TH_10P-P2.54_DC3-2.54-10PAS | DC3-2.54-10PAS | DC3-2.54-10PAS | gge119 |  | yes |  | T | DIP
7 | 1 | MB10S | D1 | MBS_L4.7-W3.8-P2.40-LS7.0-TL |  | MB10S | MDD(辰达半导体) | C2488 | LCSC |  |  | Diodes | Bridge Rectifiers | 4 | 493088 | 0.0031 | MBS_L4.7-W3.8-P2.40-LS7.0-TL | MB10S_C2488 | MB10S | UNIQUED13 |  | yes |  | T | SMT
8 | 2 | 1N4007 编带 | D2,D3 | DO-41_BD2.4-L4.7-P8.70-D0.9-RD |  | 1N4007 编带 | MDD(辰达半导体) | C19357 | LCSC |  |  | Diodes | Diodes - General Purpose | 2 | 222846 | 0.0023 | DO-41_D2.4-L4.7-P8.70 | 1N4007 编带 | 1N4007 编带 | UNIQUED14,UNIQUED15 |  | yes |  | T | DIP
9 | 2 | 5x20 环保 保险管夹/座 | F2,F3 | FUSE-TH_5X20RHOSFUSECLIP-SEAT |  | 5x20 环保 保险管夹/座 | xcfuse(旭程) | C3130 | LCSC |  |  | TVS/Fuse/Board Level Protection | Fuse Holders | 2 | 91120 | 0.0029 | FUSE-TH_5X20 | 5x20 环保 保险管夹/座 | 5x20 环保 保险管夹/座 | gge4,gge5 |  | yes |  | T | DIP
10 | 1 | UU9.8Y-10mH | L1 | FILTER-TH_UU9.8Y-10MH | 10mH | UU9.8Y-10mH | FH(风华) | C75192 | LCSC |  |  | Bead/Filter/EMI Optimization | Common Mode Filters | 4 | 4270 | 0.0424 | FILTER-TH_L16.0-W17.0-H14.0 | UU9.8Y-10mH | UU9.8Y-10mH | UNIQUEL5 |  | yes |  | T | DIP
11 | 2 | BC547-TA | Q1,Q3 | TO-92-3_L4.9-W3.7-P2.54-L |  | BC547-TA | CJ(江苏长电/长晶) | C2092 | LCSC |  |  | Triode/MOS Tube/Transistor | Bipolar Transistors - BJT | 3 | 2186 | 0.0037 | TO-92-3_L4.9-W3.7-P2.54-L | BC547-TA | BC547-TA | UNIQUEQ9,UNIQUEQ10 |  | yes |  | T | DIP
12 | 2 | BTA41-600BRG | Q2,Q4 | TOP3_L15.3-W4.5-P5.60-L |  | BTA41-600BRG | ST(意法半导体) | C9103 | LCSC |  |  | Triode/MOS Tube/Transistor | TRIACs | 3 | 7984 | 0.3307 | TOP3_L15.3-W4.5-H12.8-P5.60 | BTA41-600BRG | BTA41-600BRG | UNIQUEQ6,UNIQUEQ7 |  | yes |  | T | DIP
13 | 4 | 47kΩ | R1,R2,R5,R6 | RES-TH_BD2.3-L6.5-P10.50-D0.5 | 47kΩ | RN1/2WS47KΩFT/BA1 | Tyohm(幸亚电阻) | C385515 | LCSC |  |  | Resistors | Through Hole Resistors | 2 | 35 | 0.0018 | RES-TH_D2.3-L6.5-P10.50 | RN1/2WS47KΩFT/BA1 | 47kΩ | UNIQUER137,UNIQUER138,UNIQUER139,UNIQUER140 |  | yes |  | T | DIP
14 | 1 | 10kΩ | R3 | RES-TH_BD2.4-L6.3-P10.30-D0.6 | 10kΩ | RN1/4W10KFT/BA1 | Tyohm(幸亚电阻) | C410695 | LCSC |  |  | Resistors | Through Hole Resistors | 2 | 4955 | 0.0014 | RES-TH_BD2.4-L6.3-P10.30-D0.6 | RN1/4W10KFT/BA1 | 10kΩ | UNIQUER141 |  | yes |  | T | DIP
15 | 1 | RM10D561KD24E100 | R4 | RES-TH_L12.5-W4.4-P7.50-D0.8-LS3.0 |  | RM10D561KD24E100 | Dersonic(德尔创) | C2974807 | LCSC |  |  | TVS/Fuse/Board Level Protection | Varistors | 2 | 0 | 0.0083 | RES-TH_L12.5-W4.4-P7.50-D0.8-LS3.0 | RM10D561KD24E100 | RM10D561KD24E100 | UNIQUER142 |  | yes |  | T | DIP
16 | 1 | 220Ω | R7 | RES-TH_BD2.7-L6.2-P10.20-D0.4 | 220Ω | CR1/4W-220Ω±5%-ST26 | VO(翔胜) | C2894616 | LCSC |  |  | Resistors | Through Hole Resistors | 2 | 7750 | 0.0005 | RES-TH_BD2.2-L6.5-P10.50 | CR1/4W-220Ω±5%-ST26 | 220Ω | UNIQUER143 |  | yes |  | T | DIP
17 | 2 | 360Ω | R9,R15 | RES-TH_BD3.3-L9.0-P13.00-D0.6 | 360Ω | MFR1WSFTE52-360R | YAGEO(国巨) | C172944 | LCSC |  |  | Resistors | Through Hole Resistors | 2 | 0 | 0.0034 | RES-TH_BD3.3-L9.0-P13.00-D0.6 | MFR1WSFTE52-360R | 360Ω | gge7,gge8 |  | yes |  | T | DIP
18 | 2 | 470Ω | R10,R16 | RES-TH_BD3.3-L9.0-P13.00-D0.6 | 470Ω | RN1WS470ΩFT/BA1 | Tyohm(幸亚电阻) | C385392 | LCSC |  |  | Resistors | Through Hole Resistors | 2 | 9 | 0.0028 | RES-TH_BD3.3-L9.0-P13.00-D0.6 | RN1WS470ΩFT/BA1 | 470Ω | UNIQUER131,UNIQUER132 |  | yes |  | T | DIP
19 | 2 | 100Ω | R11,R17 | RES-TH_BD5.0-L15.5-P9.00-D0.8 | 100Ω | MOF2W-100Ω±5% FKK型 | CCO(千志电子) | C209812 | LCSC |  |  | Resistors | Through Hole Resistors | 2 | 1398 | 0.0059 | RES-TH_BD5.0-L15.5-P9.00-D0.8 | MOF2W-100Ω±5% FKK型 | 100Ω | UNIQUER134,UNIQUER135 |  | yes |  | T | DIP
20 | 4 | 1kΩ | R12,R13,R18,R19 | RES-TH_BD2.3-L6.5-P10.50-D0.5 | 1kΩ | MF1/4W-1KΩ±1%T52 | 华星机电 | C713997 | LCSC |  |  | Resistors | Through Hole Resistors | 2 | 162450 | 0.001 | RES-TH_D2.3-L6.5-P10.50 | MF1/4W-1KΩ±1%T52 | 1kΩ | UNIQUER144,UNIQUER145,UNIQUER146,UNIQUER147 |  | yes |  | T | DIP
21 | 1 | 150Ω | R24 | RES-TH_BD2.7-L6.2-P10.20-D0.4 | 150Ω | CR1/4W-100Ω±5%-ST52 | VO(翔胜) |  | LCSC |  |  | Resistors | Through Hole Resistors | 2 |  |  | RES-TH_BD2.2-L6.5-P10.50 | CR1/4W-100Ω±5%-ST52 | 150Ω | gge120 |  | yes |  | T | DIP
22 | 1 | 100Ω | R25 | RES-TH_BD2.7-L6.2-P10.20-D0.4 | 100Ω | CR1/4W-100Ω±5%-ST52 | VO(翔胜) | C2894648 | LCSC |  |  | Resistors | Through Hole Resistors | 2 | 2040 | 0.0005 | RES-TH_BD2.2-L6.5-P10.50 | CR1/4W-100Ω±5%-ST52 | 100Ω | gge121 |  | yes |  | T | DIP
23 | 2 | SRD-05VDC-SL-C | RLY1,RLY2 | RELAY-TH_SRD-XXVDC-XL-C |  | SRD-05VDC-SL-C | 松乐 | C35449 | LCSC |  |  | Relays | Power Relays | 5 | 119529 | 0.0409 | RELAY-TH_L19.2-W15.6-H15.8_1 | SRD-05VDC-SL-C | SRD-05VDC-SL-C | UNIQUERLY3,UNIQUERLY4 |  | yes |  | T | DIP
24 | 4 | Screw-Hole-M4 | SCREW1,SCREW2,SCREW3,SCREW4 | Screw-Hole-M4 |  |  |  |  |  |  | 0.0078 |  |  | 1 |  |  |  | Screw-Hole-M4 |  | gge114,gge115,gge116,gge117 |  | yes |  | T | DIP
25 | 3 | DBT50G-9.5-2P | U2,U3,U6 | CONN-TH_2P-P9.50_DBT50G-9.5-2P |  | DBT50G-9.5-2P | DORABO(地博电气) | C395958 | LCSC |  |  | Connectors | Barrier Terminal Blocks | 2 | 16742 | 0.0327 | CONN-TH_2P-P9.50_DBT50G-9.5-2P | DBT50G-9.5-2P_C395958 | DBT50G-9.5-2P | UNIQUEU53,UNIQUEU54,UNIQUEU55 |  | yes |  | T | DIP
26 | 1 | LTV-817-C | U4 | DIP-4_L4.6-W6.5-P2.54-LS7.6-BL |  | LTV-817-C | LITEON(光宝) | C109225 | LCSC |  |  | Optocoupler/LED/Digital Tube/Photoelectric Device | Optocouplers - Phototransistor Output | 4 | 12364 | 0.0067 | DIP-4_L4.6-W6.5-H3.5-LS7.62-P2.54 | LTV-817-C | LTV-817-C | UNIQUEU65 |  | yes |  | T | DIP
27 | 1 | HLK-PM01 | U8 | PWRM-TH_HLK-PM01 |  | HLK-PM01 | HI-LINK(海凌科) | C209903 | LCSC |  |  | Power Supply Chip | Power Modules | 4 | 3423 | 0.368 | PWRM-TH_L34.0-W20.0-H15.0 | HLK-PM01 | HLK-PM01 | UNIQUEU66 |  | yes |  | T | DIP
28 | 2 | MOC3021M | U10,U13 | DIP-6_L7.3-W6.5-P2.54-LS7.6-BL |  | MOC3021M | onsemi(安森美) | C5242 | LCSC |  |  | Optocoupler/LED/Digital Tube/Photoelectric Device | Optocouplers - Thyristor Signal Output | 6 | 68 | 0.037 | DIP-6_L7.3-W6.5-H3.5-LS7.62-P2.54 | MOC3021M_C5242 | MOC3021M | UNIQUEU59,UNIQUEU60 |  | yes |  | T | DIP
29 | 2 | PC817C | U11,U14 | DIP-4_L4.6-W6.5-P2.54-LS7.6-BL |  | PC817C | GOODWORK(固得沃克) | C3025068 | LCSC |  |  | Optocoupler/LED/Digital Tube/Photoelectric Device | Optocouplers - Phototransistor Output | 4 | 138744 | 0.0045 | DIP-4_L4.6-W6.5-H3.5-LS7.62-P2.54 | PC817C_C3025068 | PC817C | UNIQUEU67,UNIQUEU68 |  | yes |  | T | DIP
30 | 2 | XSD1226-307 | U12,U15 | HEATSINK-TH_XSD1226-307 |  | XSD1226-307 | XSD(鑫顺达) | C286232 | LCSC |  |  | Industrial control electrical | Heat sink/heatsink | 1 | 2163 | 0.0165 | HEATSINK-TH_XSD1226-307 | XSD1226-307 | XSD1226-307 | UNIQUEU63,UNIQUEU64 |  | yes |  | T | DIP

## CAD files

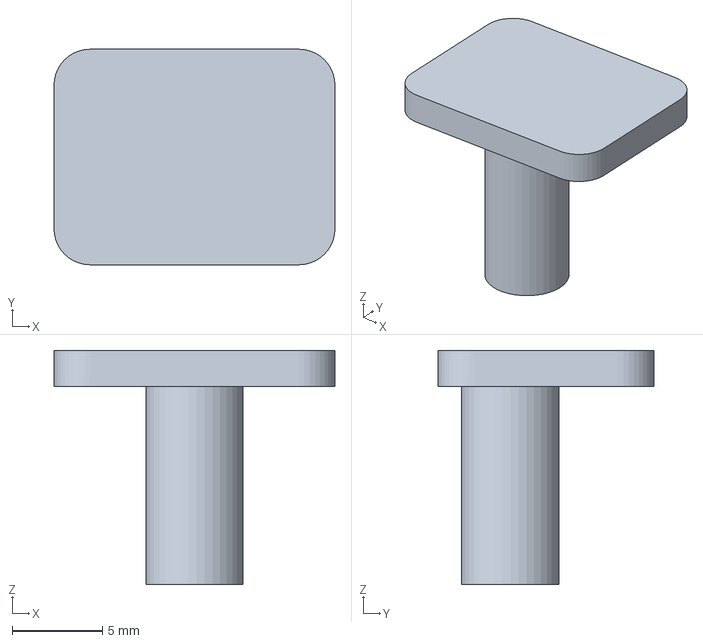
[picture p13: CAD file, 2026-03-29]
3D Model/Bottonessugiu.3MF
15.6 x 12.0 x 13.0 mm

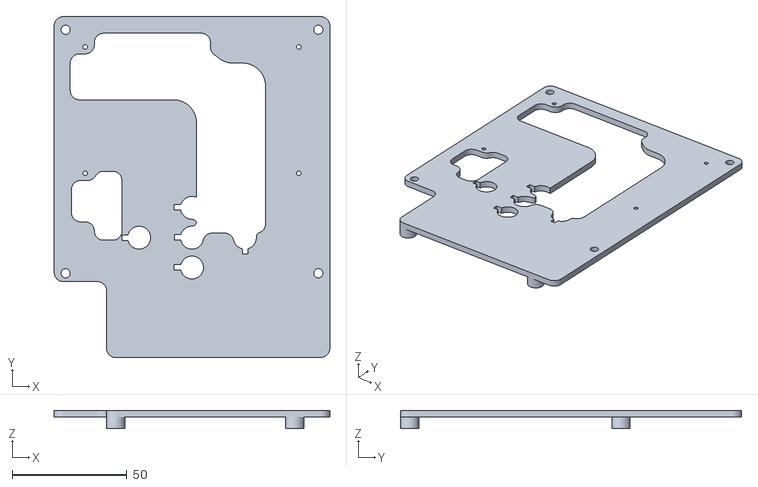
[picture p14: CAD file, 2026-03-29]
3D Model/BASE.STL
120.0 x 148.4 x 8.00

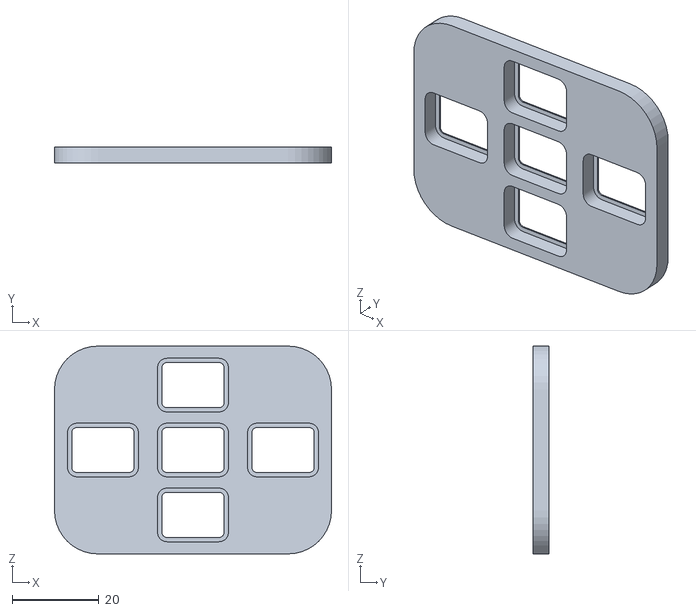
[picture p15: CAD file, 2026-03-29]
3D Model/Bottoniera.STL
64.0 x 3.80 x 48.0

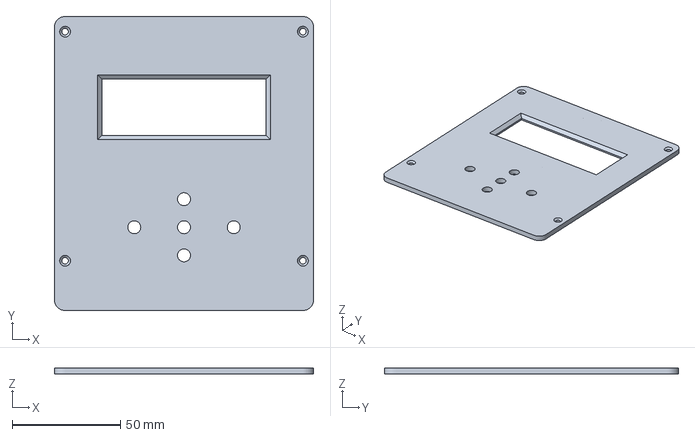
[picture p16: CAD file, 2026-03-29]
3D Model/FRONTALINO.3MF
120.0 x 136.0 x 3.00 mm

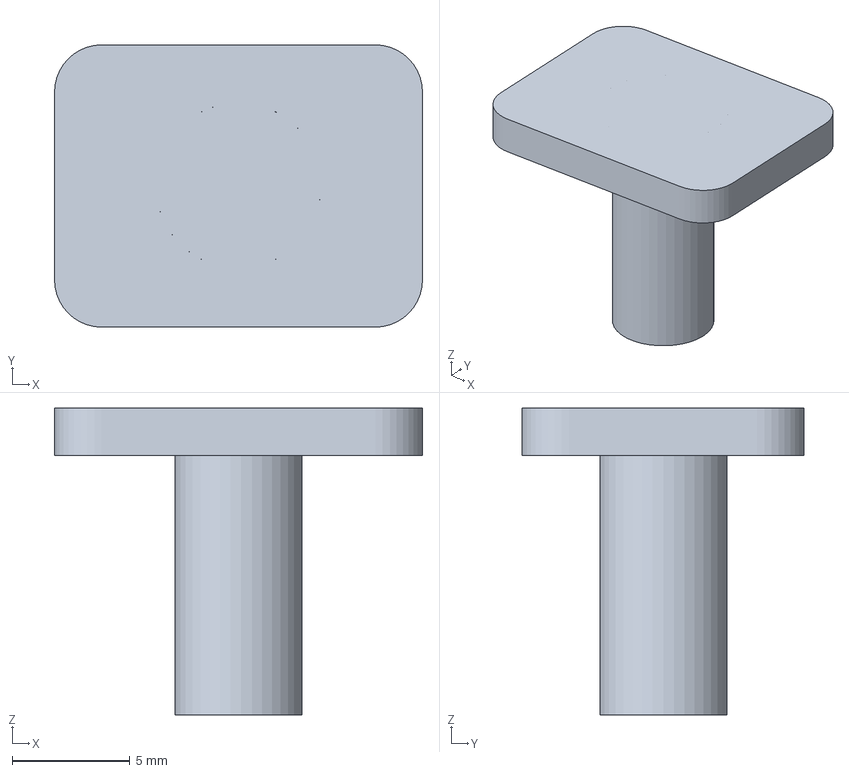
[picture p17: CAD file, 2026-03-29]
3D Model/Bottonesok.3MF
15.6 x 12.0 x 13.0 mm

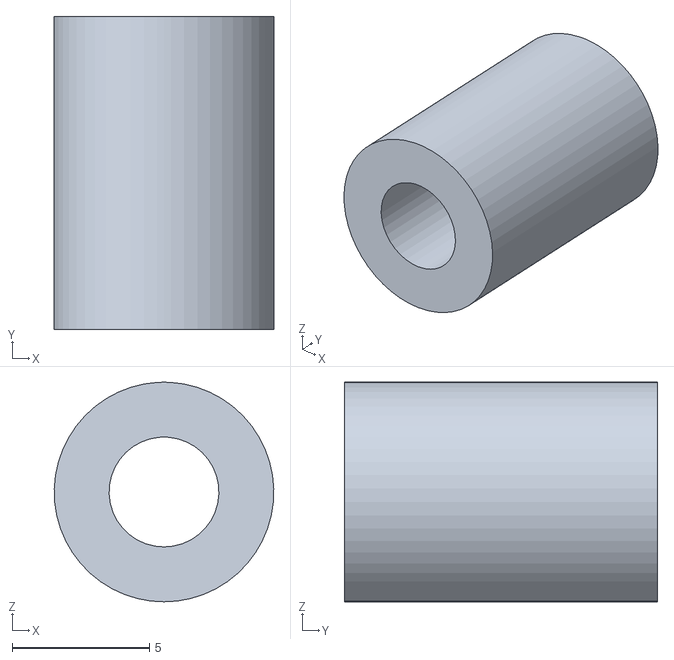
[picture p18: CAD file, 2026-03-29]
3D Model/distanziale.STL
8.00 x 11.4 x 8.00

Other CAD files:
3D Model/Bottonesxdx.3MF

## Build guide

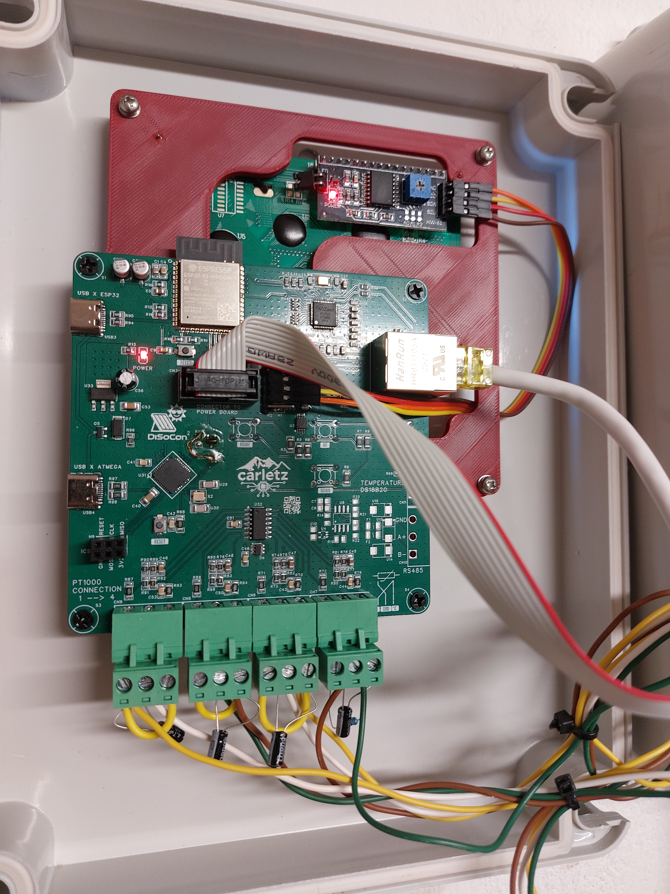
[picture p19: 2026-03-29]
Images/Control Board installed.jpg

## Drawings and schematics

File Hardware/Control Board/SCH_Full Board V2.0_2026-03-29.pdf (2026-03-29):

# USB Board Power supply

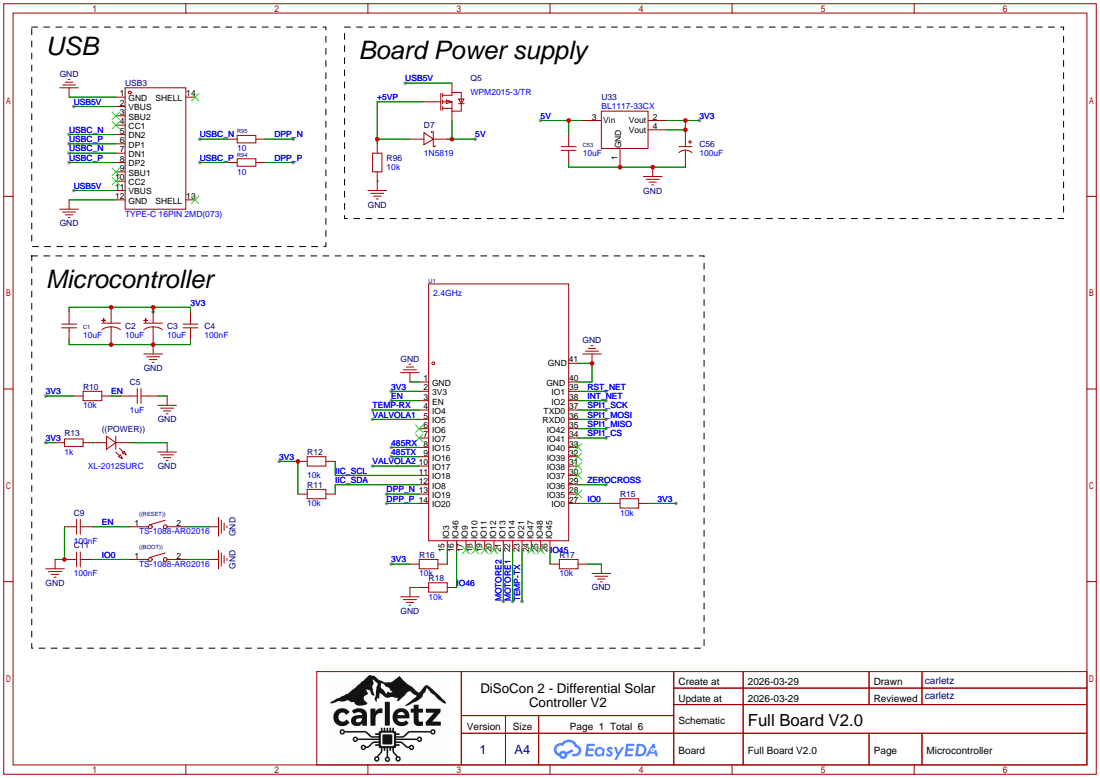
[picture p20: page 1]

Controller V2 | Create at | 2026-03-29 | Drawn | carletz DiSoCon 2 - Differential Solar

Update at | 2026-03-29 | Reviewed | carletz

Schematic | Full Board V2.0
1 | A4 | | Board | Full Board V2.0 | Page | Microcontroller

Version | Size | Page 1 Total 6

# Ethernet

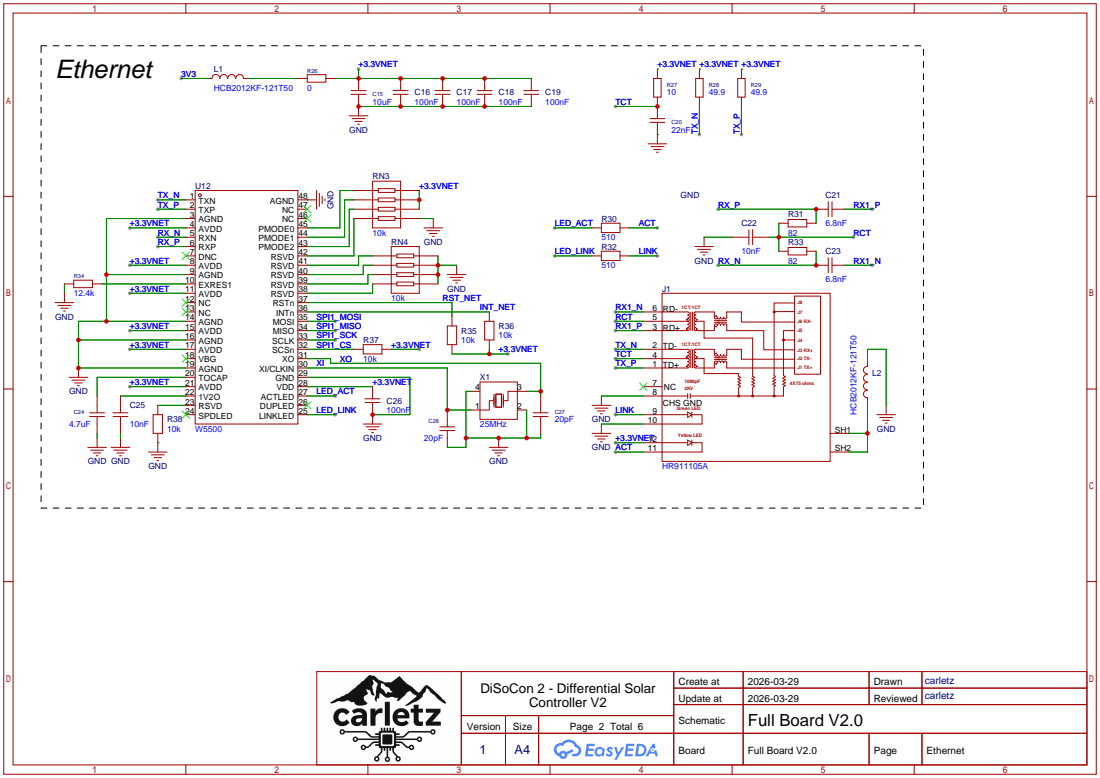
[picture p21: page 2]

Controller V2 | Create at | 2026-03-29 | Drawn | carletz DiSoCon 2 - Differential Solar

Update at | 2026-03-29 | Reviewed | carletz

Schematic | Full Board V2.0

Version | Size | Page 2 Total 6

Board | Full Board V2.0 | Page | Ethernet

# ((DOWN)) KH⁻⁶X⁶X⁸H⁻TJ

I/O

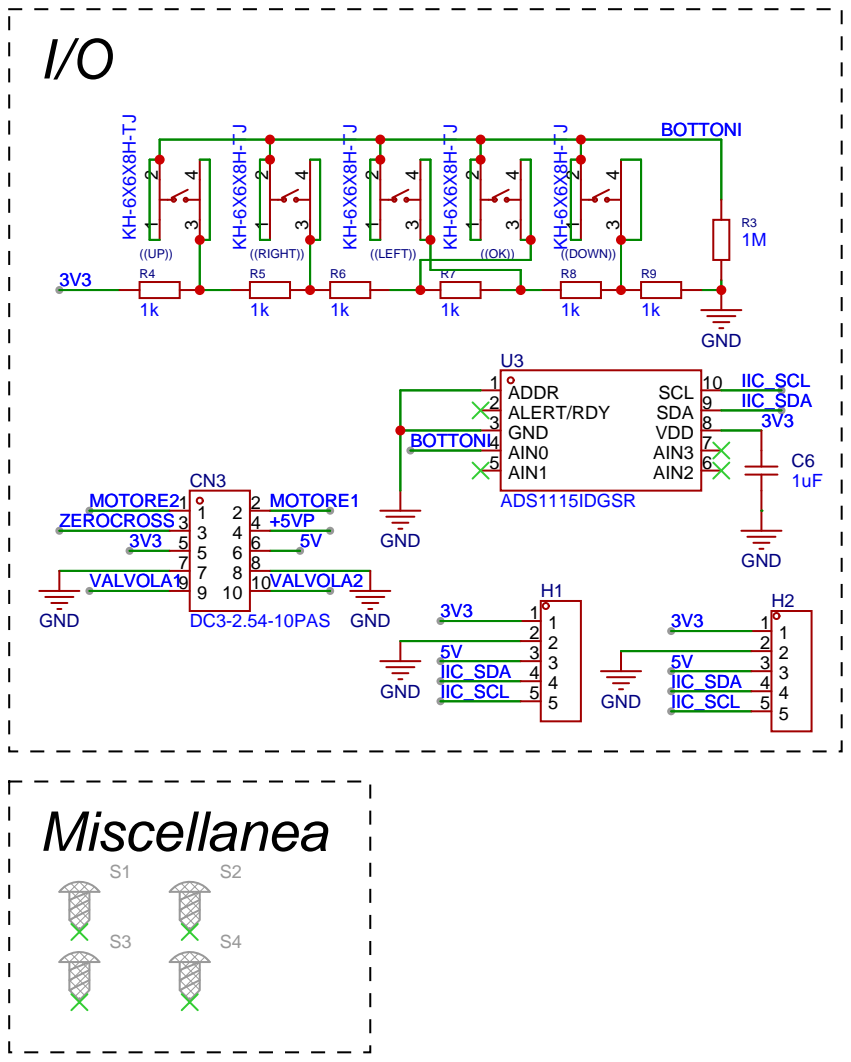
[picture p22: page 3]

Controller V2 | Create at | 2026-03-29 | Drawn | carletz DiSoCon 2 - Differential Solar

Update at | 2026-03-29 | Reviewed | carletz

Schematic | Full Board V2.0

Version | Size | Page 3 Total 6

Board | Full Board V2.0 | Page | I/O

RS485

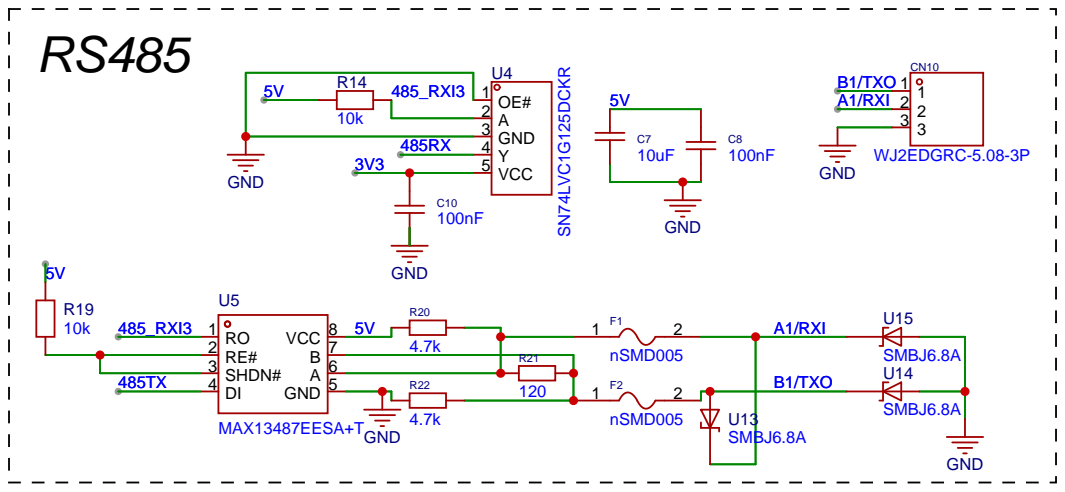
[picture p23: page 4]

Controller V2 | Create at | 2026-03-29 | Drawn | carletz DiSoCon 2 - Differential Solar

Update at | 2026-03-29 | Reviewed | carletz

Schematic | Full Board V2.0

Version | Size | Page 4 Total 6

Board | Full Board V2.0 | Page | RS485

# ATmega

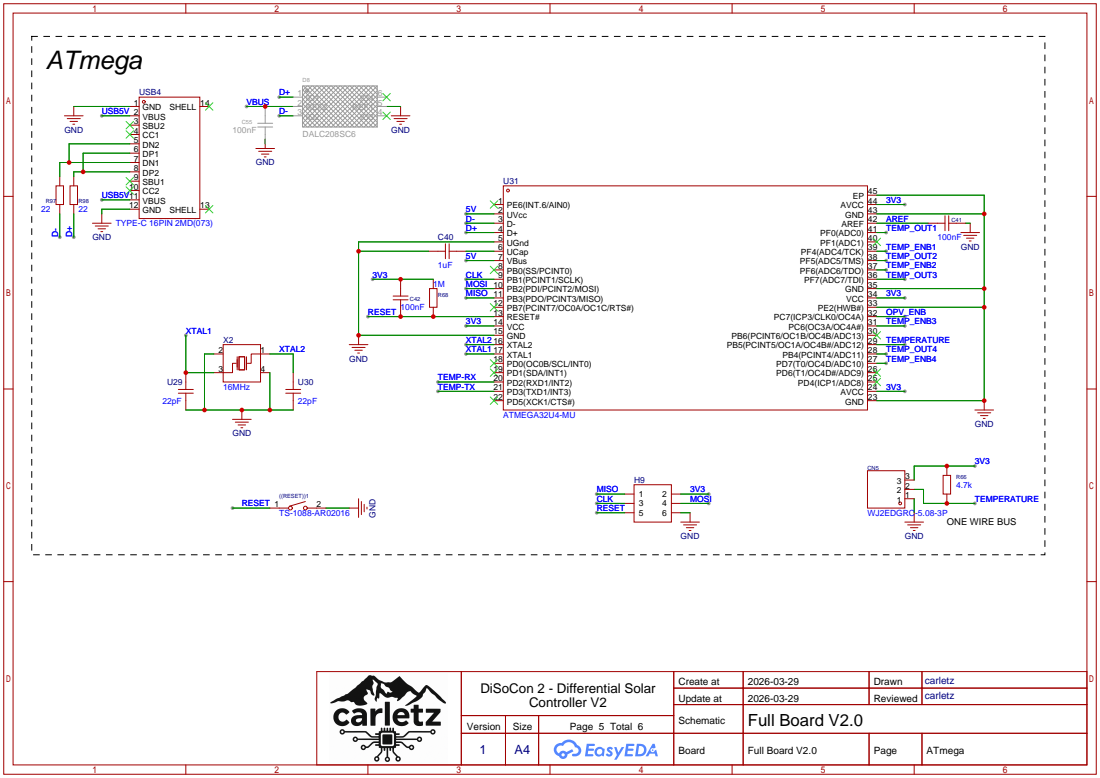
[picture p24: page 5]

Controller V2 | Create at | 2026-03-29 | Drawn | carletz DiSoCon 2 - Differential Solar

Update at | 2026-03-29 | Reviewed | carletz

Schematic | Full Board V2.0

Version | Size | Page 5 Total 6

Board | Full Board V2.0 | Page | ATmega

# 100nF GND

# Amplifier PT1000

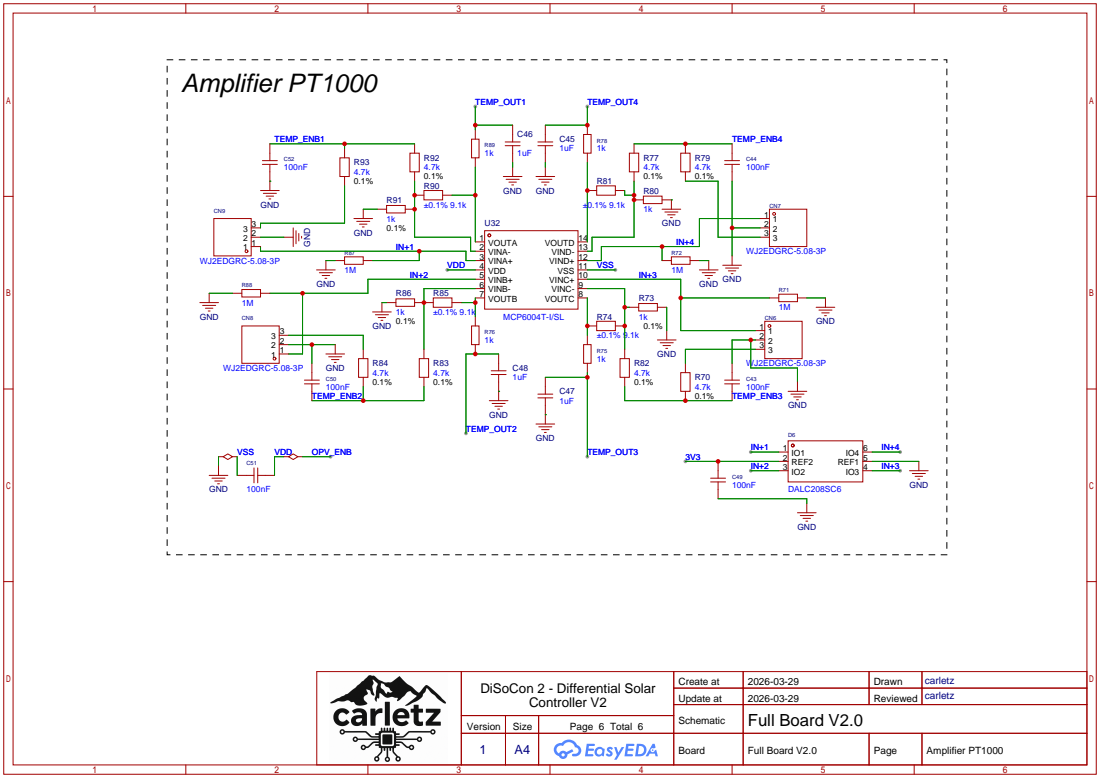
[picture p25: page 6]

VINC+ 10 VSS 11 VIND+ 12 VIND- 13 VOUTD 14

Controller V2 | Create at | 2026-03-29 | Drawn | carletz DiSoCon 2 - Differential Solar

Update at | 2026-03-29 | Reviewed | carletz

Schematic | Full Board V2.0

Version | Size | Page 6 Total 6

Board | Full Board V2.0 | Page | Amplifier PT1000

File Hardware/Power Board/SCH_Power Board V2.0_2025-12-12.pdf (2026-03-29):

# Power Supply

# Connector

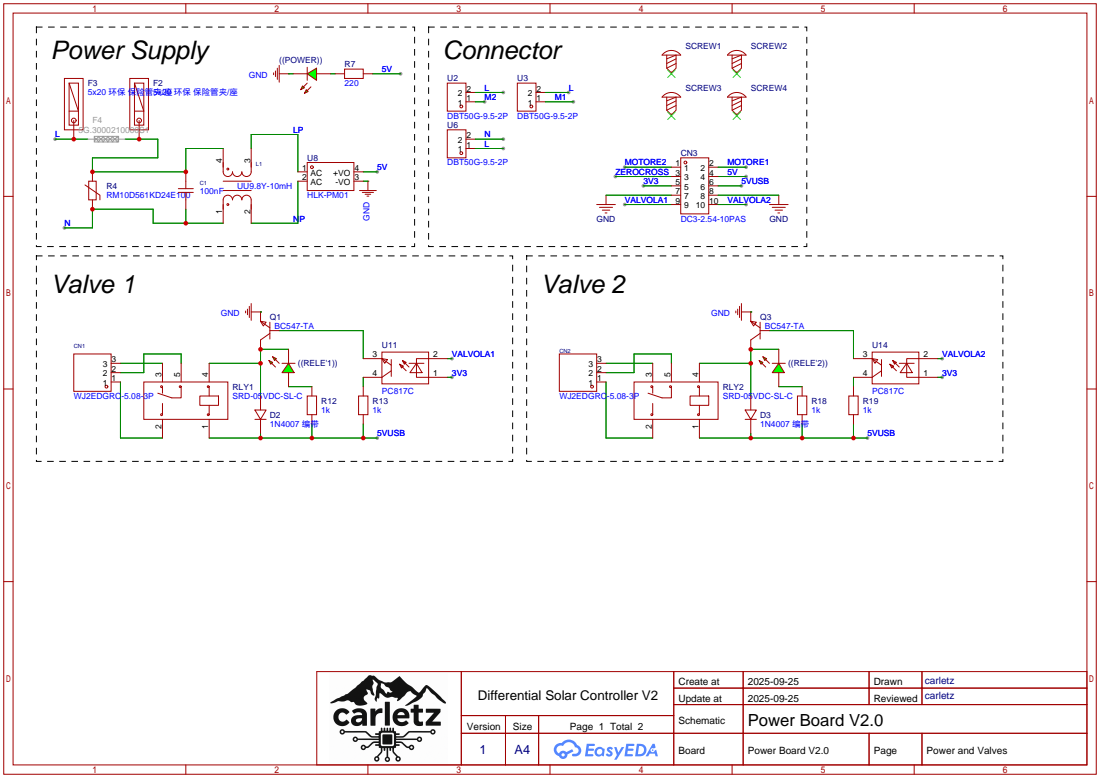
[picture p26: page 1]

Differential Solar Controller V2 | Create at | 2025-09-25 | Drawn | carletz

Update at | 2025-09-25 | Reviewed | carletz

Schematic | Power Board V2.0
1 | A4 | | Board | Power Board V2.0 | Page | Power and Valves

Version | Size | Page 1 Total 2

# Triac Firing Circuit 1

# Zero Cross Over Detection

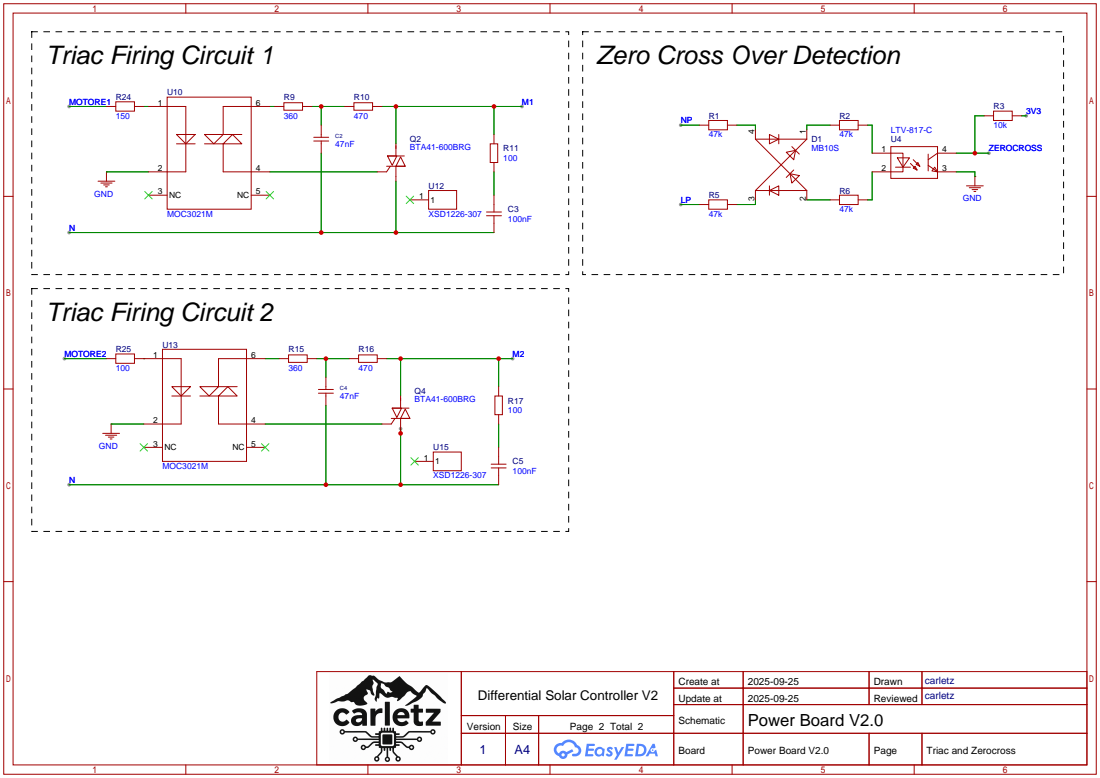
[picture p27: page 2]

Differential Solar Controller V2 | Create at | 2025-09-25 | Drawn | carletz

Update at | 2025-09-25 | Reviewed | carletz

Schematic | Power Board V2.0
1 | A4 | | Board | Power Board V2.0 | Page | Triac and Zerocross

Version | Size | Page 2 Total 2

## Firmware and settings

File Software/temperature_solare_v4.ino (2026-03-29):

/**
 * temperature_solare_v3.ino
 * Lettura 4 canali PT100/PT1000 via OPV → ADC ATmega32U4
 * Trasmissione via RS485 (Serial1, UART hardware del 32U4)
 *
 * Hardware: ATmega32U4 (Arduino Leonardo / Micro / PCB custom)
 *
 * Lettura OneWire DS18B20: commentata, non usata in questa versione.
 */

// #include <OneWire.h>           // -- DS18B20: non usato --
// #include <DallasTemperature.h> // -- DS18B20: non usato --

#include <avr/sleep.h>   // ADC Noise Reduction Mode
#include <avr/interrupt.h>

// ============================================================
//  PIN MAPPING  (ATmega32U4 / PCB custom)
//  Define originali verificate sul campo — non modificare.
// ============================================================

// Pin di enable per ogni canale
static const uint8_t ENB_PINS[4] = { A3, A1, 5, 6 };

// Delay di stabilizzazione per canale (ms) — aumentare per cavi lunghi o RC alto
// CH0: cavi lunghi → 80ms | altri: 20ms
static const uint8_t CHANNEL_SETTLE_MS[4] = { 80, 20, 20, 20 };

// Numero di campioni ADC per canale — più campioni = più robusto al rumore
// CH0: cavo lungo vicino a 230V → 60 campioni | altri: 20
static const uint8_t CHANNEL_SAMPLES[4] = { 60, 20, 20, 20 };

// Filtro IIR (media mobile esponenziale) per canale
// valore_filtrato = ALPHA * lettura_nuova + (1-ALPHA) * valore_precedente
// Alpha basso = filtro aggressivo (lento ma stabile)
// Alpha alto  = filtro leggero (veloce ma più rumoroso)
// CH0: 0.3 (compromesso tra reattività e stabilità) | altri: 0.5
static const float IIR_ALPHA[4] = { 0.5f, 0.5f, 0.5f, 0.5f };
static float iirFiltered[4] = { -999.0f, -999.0f, -999.0f, -999.0f }; // -999 = non inizializzato

// Pin ADC per ogni canale
//   ch3: pin 8 = PB4 = ADC11 sul 32U4, funzionante come analogRead(8)
static const uint8_t ADC_PINS[4] = { A5, A2, A0, 8 };

// Pin enable dello stadio OPV
static const uint8_t OPV_ENB_PIN = 13;

// ============================================================
//  RS485  –  ATmega32U4 ha due UART hardware:
//    Serial  = USB CDC  (debug / monitor seriale)
//    Serial1 = pin 0/1  (TX1/RX1) → transceiver RS485
//  Pin DE/RE del transceiver (HIGH = trasmissione, LOW = ricezione)
// ============================================================
static const uint8_t RS485_DE_PIN = 2; // Cambia se necessario; -1 = non usato

// ============================================================
//  CALIBRAZIONE PT1000  (circuito: MCP6004 + partitore 4.7kΩ, Vcc=3.3V)
// ============================================================
//
//  Amplificatore non-invertente: G = 1 + R_fb/R_gain = 1 + 9100/1000 = 10.1
//  Partitore di offset 4.7kΩ/4.7kΩ → V_offset ≈ 1.65V sull'ingresso inv.
//  La curva V_out(T) è monotona e quasi lineare nel range di lavoro,
//  quindi la conversione lineare è adeguata:
//
//    T[°C] = ADC_GAIN * adcMedian + ADC_OFFSET
//
//  ── Come calibrare a 2 punti ────────────────────────────────────────
//  1. Sonda a T1 nota (es. 25.0°C) → leggi adcMedian → ADC1
//  2. Sonda a T2 nota (es. 80.0°C) → leggi adcMedian → ADC2
//     ADC_GAIN   = (T2 - T1) / (float)(ADC2 - ADC1)
//     ADC_OFFSET = T1 - ADC_GAIN * ADC1
//
//  ── Valori attuali (verificati sul campo nel codice originale) ───────
// Coefficienti di calibrazione per canale
// Tutti i canali usano gli stessi coefficienti originali
// Per calibrare a 2 punti: GAIN=(T2-T1)/(ADC2-ADC1), OFFSET=T1-GAIN*ADC1
static const float CHAN_GAIN[4]   = { 0.153479f, 0.153479f, 0.153479f, 0.153479f };
static const float CHAN_OFFSET[4] = {   -27.23f,   -27.23f,   -27.23f,   -27.23f };

//  ── Correzione fine per canale (in decimi di °C) ────────────────────
//  Compensa disomogeneità tra i 4 canali (tolleranze R, offset OPV).
//  NOTA: il +50 su ch0 (+5.0°C) era nel codice originale — verificare
//  se è una correzione hardware reale o un residuo di debug.
// Correzione offset per canale (decimi di °C)
static const int16_t CHANNEL_TRIM[4] = { 0, 0, 0, 0 };

// ============================================================
//  RILEVAMENTO SONDA DISCONNESSA / IN CORTOCIRCUITO
// ============================================================
//
//  Con PT100 su partitore 5V:
//    – Circuito aperto  (sonda scollegata): ADC → 1023 (tensione massima)
//    – Cortocircuito    (PT → 0Ω):         ADC → 0
//  Definiamo soglie di validità con margine di sicurezza.
//
//  Calcola i tuoi limiti:
//    ADC_MIN = adcAvg a T_min operativa (es. -30°C) – margine
//    ADC_MAX = adcAvg a T_max operativa (es. +200°C) + margine
static const uint16_t ADC_FAULT_LOW  =  10;   // sotto → cortocircuito
static const uint16_t ADC_FAULT_HIGH = 1010;  // sopra → circuito aperto

// Valore sentinella per errore (in decimi di °C): 32767 = +3276.7°C
// Valore positivo inequivocabile → il master lo interpreta come fault (> 30000)
static const int16_t TEMP_ERROR = 32767;

// ============================================================
//  CAMPIONAMENTO ADC con Noise Reduction Mode (ATmega32U4)
// ============================================================
//
//  Il processore entra in ADC Noise Reduction Sleep durante la conversione:
//  clock CPU, I/O digitali e altri moduli vengono silenziati, riducendo
//  il rumore sul bus analogico di ~2-4 LSB rispetto a analogRead() normale.
//
//  Dopo ADC_SAMPLES letture, i valori vengono ordinati e viene calcolata
//  la mediana (più robusta della media contro picchi di disturbo).

// Numero massimo di campioni possibile (dimensiona il buffer in adcMedian)
static const uint8_t ADC_SAMPLES_MAX = 60;

volatile bool adcDone = false;

// ISR risveglio dal sleep (basta uscire dal modo sleep)
ISR(ADC_vect) {
  adcDone = true;
}

/**
 * Esegue una singola conversione ADC in Noise Reduction Mode.
 * Restituisce il valore grezzo a 10 bit.
 */
static uint16_t adcReadNoiseFree(uint8_t pin) {
  // Usa analogRead() normale per impostare il MUX correttamente,
  // poi ripete la conversione in sleep mode per la lettura effettiva.
  analogRead(pin); // warm-up: imposta MUX e scarica capacità di campionamento

  adcDone = false;
  ADCSRA |= (1 << ADIE);          // abilita interrupt ADC
  set_sleep_mode(SLEEP_MODE_ADC); // Noise Reduction Mode
  sei();
  sleep_enable();
  sleep_cpu();                    // la CPU si ferma; l'ADC converte da solo
  sleep_disable();
  ADCSRA &= ~(1 << ADIE);         // disabilita interrupt ADC

  // Leggi risultato (ADCL va letto per primo per bloccare ADCH)
  uint16_t result = ADC;
  return result;
}

/**
 * Campiona il canale ADC `pin` per `n` volte, ordina i valori e
 * restituisce la mediana (resistente a picchi/glitch).
 */
static uint16_t adcMedian(uint8_t pin, uint8_t n) {
  uint16_t buf[ADC_SAMPLES_MAX]; // buffer dimensionato sul massimo possibile
  for (uint8_t i = 0; i < n; i++) {
    buf[i] = adcReadNoiseFree(pin);
    // Nessun delay: il Noise Reduction Mode già garantisce conversioni pulite.
    // Se il circuito ha RC lento, aggiungi delayMicroseconds(200) qui.
  }

  // Insertion sort (efficiente per n piccolo, niente heap dinamico)
  for (uint8_t i = 1; i < n; i++) {
    uint16_t key = buf[i];
    int8_t j = i - 1;
    while (j >= 0 && buf[j] > key) {
      buf[j + 1] = buf[j];
      j--;
    }
    buf[j + 1] = key;
  }

  // Mediana: media dei due centrali (n pari) per evitare bias
  return (buf[n / 2 - 1] + buf[n / 2]) / 2;
}

// ============================================================
//  DATI GLOBALI
// ============================================================

// temp_value[0..3]: temperature canali OPV in decimi di °C
//   Es.: 235 = 23.5°C | TEMP_ERROR (0x8000) = fault
static int16_t   temp_value[4];
static uint16_t  adcRawDebug[4]; // DEBUG: valori ADC grezzi per calibrazione
static uint32_t  lastReadTime = 0;
static const uint32_t READ_INTERVAL = 15000; // ms

// -- DS18B20: strutture commentate --
// OneWire          oneWire(9);
// DallasTemperature sensors(&oneWire);
// static int16_t   ds_temp[12];
// static uint8_t   numDS = 0;

// ============================================================
//  SETUP
// ============================================================

void setup() {
  // USB CDC per debug (Serial su 32U4 è virtuale, non usa pin fisici)
  Serial.begin(9600);

  // UART hardware Serial1 (pin 0=RX1, 1=TX1) per RS485
  Serial1.begin(9600);
  if (RS485_DE_PIN >= 0) {
    pinMode(RS485_DE_PIN, OUTPUT);
    digitalWrite(RS485_DE_PIN, HIGH); // sempre in TX (half-duplex)
  }

  // OPV e canali spenti all'avvio
  pinMode(OPV_ENB_PIN, OUTPUT);
  digitalWrite(OPV_ENB_PIN, LOW);
  for (uint8_t i = 0; i < 4; i++) {
    pinMode(ENB_PINS[i], OUTPUT);
    digitalWrite(ENB_PINS[i], LOW);
  }

  // AVCC (pin 44) è collegato a 3V3 sullo schematico → referenza ADC = 3.3V
  // AREF (pin 42) ha solo il condensatore di bypass → non usare EXTERNAL.
  analogReference(DEFAULT); // usa AVCC = 3V3

  // -- DS18B20: init commentato --
  // sensors.begin();
  // numDS = min(sensors.getDeviceCount(), 12);

  Serial.println(F("Sistema pronto."));
}

// ============================================================
//  LETTURA CANALI OPV
// ============================================================

void opv_readChannels() {
  digitalWrite(OPV_ENB_PIN, HIGH);
  delay(100); // attendi stabilizzazione alimentazione OPV (era 30ms, insufficiente)

  for (uint8_t i = 0; i < 4; i++) {
    digitalWrite(ENB_PINS[i], HIGH);
    delay(CHANNEL_SETTLE_MS[i]); // stabilizzazione RC: variabile per canale (cavi lunghi → più tempo)

    uint16_t adcVal = adcMedian(ADC_PINS[i], CHANNEL_SAMPLES[i]);
    adcRawDebug[i] = adcVal; // DEBUG: salva ADC grezzo per calibrazione

    digitalWrite(ENB_PINS[i], LOW);

    // ── Rilevamento fault ──────────────────────────────────
    if (adcVal <= ADC_FAULT_LOW) {
      temp_value[i] = TEMP_ERROR; // PT in cortocircuito
      iirFiltered[i] = -999.0f;  // reset filtro
      Serial.print(F("CH")); Serial.print(i); Serial.println(F(": CORTOCIRCUITO"));
      continue;
    }
    if (adcVal >= ADC_FAULT_HIGH) {
      temp_value[i] = TEMP_ERROR; // PT scollegata / circuito aperto
      iirFiltered[i] = -999.0f;  // reset filtro
      Serial.print(F("CH")); Serial.print(i); Serial.println(F(": SONDA ASSENTE"));
      continue;
    }

    // ── Conversione ADC → °C (PT100/PT1000 linearizzata) ──
    float tempC = CHAN_GAIN[i] * (float)adcVal + CHAN_OFFSET[i];

    // ── Filtro IIR ─────────────────────────────────────────
    if (iirFiltered[i] <= -998.0f) {
      iirFiltered[i] = tempC; // prima lettura: inizializza senza filtrare
    } else {
      iirFiltered[i] = IIR_ALPHA[i] * tempC + (1.0f - IIR_ALPHA[i]) * iirFiltered[i];
    }

    temp_value[i] = (int16_t)(iirFiltered[i] * 10.0f) + CHANNEL_TRIM[i];
  }

  digitalWrite(OPV_ENB_PIN, LOW);
}

// ============================================================
//  DEBUG SU USB SERIAL
// ============================================================

void debug_print() {
  Serial.print(F("Temp [°C]: "));
  for (uint8_t i = 0; i < 4; i++) {
    Serial.print(F("CH")); Serial.print(i); Serial.print('=');
    if (temp_value[i] == TEMP_ERROR) {
      Serial.print(F("FAULT"));
    } else {
      Serial.print(temp_value[i] / 10.0f, 1);
      Serial.print(F("°C"));
    }
    Serial.print(' ');
  }
  Serial.println();

  // DEBUG CALIBRAZIONE: stampa valori ADC grezzi
  Serial.print(F("ADC raw:   "));
  for (uint8_t i = 0; i < 4; i++) {
    // Ri-legge adcRaw tramite variabile esterna — vedi opv_readChannels
    Serial.print(F("CH")); Serial.print(i); Serial.print('=');
    Serial.print(adcRawDebug[i]);
    Serial.print(' ');
  }
  Serial.println();
}

// ============================================================
//  INVIO RS485  –  protocollo ASCII "<idx>x<decimi_C>\n"
// ============================================================
//  Il master legge registri 0..3.
//  TEMP_ERROR (0x8000 = -32768 come int16_t) segnala fault al master.

void rs485_send() {
  for (uint8_t i = 0; i < 4; i++) {
    Serial1.print(i);
    Serial1.print('x');
    Serial1.print(temp_value[i]);
    Serial1.print('\n');
  }
  Serial1.flush();
}

// ============================================================
//  LOOP
// ============================================================

void loop() {
  uint32_t now = millis();
  if (now - lastReadTime >= READ_INTERVAL) {
    lastReadTime = now;

    opv_readChannels();
    debug_print();
    rs485_send();

    // -- DS18B20: blocco commentato --
    // sensors.requestTemperatures();
    // for (uint8_t i = 0; i < numDS; i++) {
    //   float t = sensors.getTempCByIndex(i);
    //   ds_temp[i] = (t == DEVICE_DISCONNECTED_C) ? TEMP_ERROR : (int16_t)(t * 10.0f);
    // }
  }
}

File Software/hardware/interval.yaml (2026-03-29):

interval:
  # ─────────────────────────────────────────────
  #  1s — scroll display + soft start pompa PWM
  # ─────────────────────────────────────────────
  - interval: 1s
    then:
      - lambda: |-
          id(centrale_scroll_index) += 1;
          if (id(centrale_scroll_index) > 100) {
            id(centrale_scroll_index) = 0;
          }
      # Rampa soft start pompa PWM
      - lambda: |-
          if (id(pwm_soft_start_active)) {
            if (id(pwm_soft_current) < id(pwm_soft_target)) {
              id(pwm_soft_current) += 10;
              if (id(pwm_soft_current) > id(pwm_soft_target)) {
                id(pwm_soft_current) = id(pwm_soft_target);
              }
            } else if (id(pwm_soft_current) > id(pwm_soft_target)) {
              id(pwm_soft_current) -= 10;
              if (id(pwm_soft_current) < id(pwm_soft_target)) {
                id(pwm_soft_current) = id(pwm_soft_target);
              }
            }
            id(pwm_percentuale).publish_state(id(pwm_soft_current));
            id(pwm_attivo) = (id(pwm_percentuale).state > 0);
            if (id(pwm_soft_current) == id(pwm_soft_target)) {
              id(pwm_soft_start_active) = false;
            }
            id(aggiorna_stato_pompa1_mqtt).execute();
          }
      # Lettura UART temperature ATmega — drena il buffer ogni secondo,
      # pubblica ogni canale individualmente solo se il valore è valido.
      # La pubblicazione è indipendente per canale: una sonda guasta
      # non blocca la lettura delle altre.
      - lambda: |-
          uint8_t byte = 0;
          static std::string line = "";

          while (id(uart_bus).available()) {
            if (!id(uart_bus).read_byte(&byte)) break;

            if (byte == '\n') {
              if (line.length() > 2 && line[1] == 'x') {
                char type = line[0];
                int idx = type - '0';
                int temp_value = atoi(line.substr(2).c_str());

                if (idx >= 0 && idx <= 3) {
                  if (temp_value > 30000) {
                    ESP_LOGW("custom", "ERRORE: Sonda fault (canale %c)", type);
                    // non pubblica nulla su questo canale, gli altri non sono toccati
                  } else {
                    float temperature = temp_value / 10.0;
                    id(last_uart_receive_time) = millis();

                    if (idx == 0) {
                      id(temp_pannelli_solari).publish_state(temperature);
                    } else if (idx == 1) {
                      id(temp_solare_1).publish_state(temperature);
                    } else if (idx == 2) {
                      id(temp_solare_2).publish_state(temperature);
                    } else if (idx == 3) {
                      id(temp_acs).publish_state(temperature);
                    }
                    ESP_LOGD("custom", "CH%d: %.1f°C", idx, temperature);
                  }
                }
              }
              line = "";
            } else {
              line += (char)byte;
              if (line.length() > 20) {
                ESP_LOGW("custom", "Buffer UART overflow, riga scartata.");
                line = "";
              }
            }
          }

          // Watchdog: pubblica NAN solo se per 30s non arriva NULLA (ATmega morto)
          if (id(last_uart_receive_time) > 0 &&
              (millis() - id(last_uart_receive_time) > 30000)) {
            ESP_LOGE("custom", "WATCHDOG: nessun dato UART da oltre 30s!");
            id(temp_pannelli_solari).publish_state(NAN);
            id(temp_solare_1).publish_state(NAN);
            id(temp_solare_2).publish_state(NAN);
            id(temp_acs).publish_state(NAN);
            id(last_uart_receive_time) = millis();
          }

  # ─────────────────────────────────────────────
  #  3s — logica controllo PWM pompa solare
  # ─────────────────────────────────────────────
  - interval: 3s
    then:
      - lambda: |-
          // Se la pompa è in modalità manuale, la logica automatica non interviene
          if (id(pompa1_manual_mode)) return;

          // Sicurezza locale commutazione S2->S1: se S2 supera la soglia+2C
          // e siamo ancora su S2, forza la commutazione indipendentemente dal binary_sensor
          if (!id(stato_serbatoio_attivo) &&
              !isnan(id(temp_solare_2).state) &&
              id(temp_solare_2).state > id(setpoint_max_S2).state + 2.0f) {
            id(stato_serbatoio_attivo) = true;
            id(valvola1).turn_on();
            ESP_LOGW("centrale", "SAFETY: commutazione forzata su S1, S2=%.1fC", id(temp_solare_2).state);
          }
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

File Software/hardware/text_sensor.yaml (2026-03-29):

text_sensor:
  - platform: version
    name: "Solare Versione"
    id: versione_esphome
    on_value:
      then:
        - mqtt.publish:
            topic: ${main_topic}/${diagnostica_topic}/Versione
            payload: !lambda 'return x;'
    web_server:
      sorting_group_id: ordine_varie
      sorting_weight: 1

  - platform: ethernet_info
    ip_address:
      name: "Solare IP"
      id: ip_address
      web_server:
        sorting_group_id: ordine_varie
    dns_address:
      name: "Solare DNS"
      id: dns_address
      web_server:
        sorting_group_id: ordine_varie
    mac_address:
      name: "Solare MAC"
      id: mac_address
      web_server:
        sorting_group_id: ordine_varie

  - platform: template
    name: "Uptime"
    icon: mdi:history
    update_interval: 10s
    state_topic: "${main_topic}/${diagnostica_topic}/Uptime"
    lambda: |-
      uint32_t s = (uint32_t) id(uptime_sensor_raw).state;
      uint32_t d = s / 86400;
      s %= 86400;
      uint32_t h = s / 3600;
      s %= 3600;
      uint32_t m = s / 60;
      s %= 60;
      char buf[32];
      if (d > 0)
        sprintf(buf, "%dd %02d:%02d:%02d", d, h, m, s);
      else
        sprintf(buf, "%02d:%02d:%02d", h, m, s);
      return {buf};
    web_server:
      sorting_group_id: ordine_varie
      sorting_weight: 1     

  - platform: template
    name: "Serbatoio In Uso"
    lambda: |-
      if (id(use_solare_1).state) {
        return std::string("Serbatoio 1 in uso");
      } else {
        return std::string("Serbatoio 2 in uso");
      }
    update_interval: 10s
    on_value:
      then:
        - mqtt.publish:
            topic: ${main_topic}/${serbatoio_topic}/In Uso/state
            payload: !lambda 'return x;'
            retain: true
    web_server:
      sorting_group_id: ordine_temp
      sorting_weight: -2

  - platform: template
    name: "Trend Temperatura Pannelli"
    id: temp_trend_pannelli_sensor
    lambda: |-
      int t = (int)id(temp_trend_pannelli).state;
      if (t == 1) {
        return {"🔺 Aumento"};
      } else if (t == -1) {
        return {"🔻 Calo"};
      } else {
        return {"➖ Stabile"};
      }
    on_value:
      then:
        - mqtt.publish:
            topic: ${main_topic}/${sonde_topic}/Trend Pannelli Solari/Testo/state
            payload: !lambda 'return x;'
            retain: True
    web_server:
      sorting_group_id: ordine_temp
      sorting_weight: -1

  - platform: template
    name: "Tempo totale pannelli > 80°C"
    lambda: |-
      int sec = id(tempo_totale) % 60;
      int min = id(tempo_totale) / 60;
      char buffer[10];
      sprintf(buffer, "%02d:%02d", min, sec);
      return {buffer};
    on_value:
      then:
        - mqtt.publish:
            topic: ${main_topic}/${pannelli_topic}/Tempi/Totale/state
            payload: !lambda 'return x;'
            retain: true
    web_server:
      sorting_group_id: ordine_tempi
      sorting_weight: 10

  - platform: template
    name: "Tempo oggi pannelli > 80°C"
    lambda: |-
      int sec = id(tempo_giorno) % 60;
      int min = id(tempo_giorno) / 60;
      char buffer[10];
      sprintf(buffer, "%02d:%02d", min, sec);
      return {buffer};
    on_value:
      then:
        - mqtt.publish:
            topic: ${main_topic}/${pannelli_topic}/Tempi/Giorno/state
            payload: !lambda 'return x;'
            retain: true
    web_server:
      sorting_group_id: ordine_tempi
      sorting_weight: 11

  - platform: template
    name: "Tempo settimana pannelli > 80°C"
    lambda: |-
      int sec = id(tempo_settimana) % 60;
      int min = id(tempo_settimana) / 60;
      char buffer[10];
      sprintf(buffer, "%02d:%02d", min, sec);
      return {buffer};
    on_value:
      then:
        - mqtt.publish:
            topic: ${main_topic}/${pannelli_topic}/Tempi/Settimana/state
            payload: !lambda 'return x;'
            retain: true
    web_server:
      sorting_group_id: ordine_tempi
      sorting_weight: 12

  - platform: template
    name: "Tempo mese pannelli > 80°C"
    lambda: |-
      int sec = id(tempo_mese) % 60;
      int min = id(tempo_mese) / 60;
      char buffer[10];
      sprintf(buffer, "%02d:%02d", min, sec);
      return {buffer};
    on_value:
      then:
        - mqtt.publish:
            topic: ${main_topic}/${pannelli_topic}/Tempi/Mese/state
            payload: !lambda 'return x;'
            retain: true
    web_server:
      sorting_group_id: ordine_tempi
      sorting_weight: 13
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
